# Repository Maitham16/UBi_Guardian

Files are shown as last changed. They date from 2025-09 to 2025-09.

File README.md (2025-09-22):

# UBi-Guardian — Software Stack

Smart edge-AI guardian that senses risks in small aquatic habitats and restores balance with gentle air bursts.  
This repo contains all software pieces: ESP32 firmware, data collector, alerts, dashboard and the ML model assets.

---

## 1) Repo layout

```
/firmware/
  esp32s3.ino                # main firmware (ESP32-S3, Arduino)
  model_data.h               # TFLite model as a C array (included by firmware)
  model_data.cpp             # separate TU
  esp32s3_ripple_classifier.keras # model
  esp32s3_ripple_classifier.tflite # model
/ml/
  train_model.ipynb          # training model
  data_preprocessing.py      # prepare data to train
/server/
  main.py                    # FastAPI collector + CSV logging + Discord alerts
  data_preprocessing.py      # one time script
  Data_collector_phase_1.py  # early phase script for data collector
  dashboard.html             # zero-dependency, opens in a browser
  data/                      # dataset
    telemetry.csv            # timeseries real recorded data
    events.csv               # alerts & pump recommendations
    telemetry.ndjson         # raw backup
    training.csv             # train dataset
```

---

## 2) Quick start

### A) Collector + Alerts (FastAPI)
Requirements: Python 3.9+.

```bash
cd server
python -m venv .venv
source .venv/bin/activate
pip install fastapi uvicorn requests
```

Discord alerts:
- The server already includes a **built-in default webhook URL** in `main.py` (you can replace the `DEFAULT_WEBHOOK` string).
- Alternatively set an env var to override at runtime:
  ```bash
  export DISCORD_WEBHOOK_URL="https://discord.com/api/webhooks/XXX/YYY"
  ```

Run:
```bash
uvicorn main:app --host 0.0.0.0 --port 5001
```

You now have:
- POST `http://<server>:5001/ingest`  # device posts telemetry here
- GET  `/health`, `/latest`, `/export.csv`, `/events.csv`
- POST `/alert/test` (sends a demo alert to Discord)
- POST `/alert/webhook` (persist a new webhook if no env var is set)

> Data files are written to `server/data/` (created automatically).

---

### B) Firmware (ESP32-S3, Arduino)
1. Open **Arduino IDE** (2.x), install:
   - **ESP32** board support, select an **ESP32-S3** dev board.
   - Libraries: `OneWire`, `DallasTemperature`, `Adafruit AHTX0`, `Adafruit VEML7700`, `Adafruit MLX90614`, `Adafruit BMP085/BMP180`, `ESPmDNS`, `Preferences`.

2. Pins (as in the code):
   - I²C: `SDA=8`, `SCL=9`
   - I²S mic (INMP441): `BCLK=18`, `LRCL=17`, `DIN=16`, `SAMPLE_RATE=16000`
   - Relay: `GPIO15`
   - OneWire DS18B20: `GPIO6`
   - TDS ADC pin: `GPIO4`

3. ML model embedding (already provided):
   - We ship `model_data.h/.cpp` with `esp32s3_ripple_classifier_tflite` byte array.
   - If you retrain: regenerate the header from the `.tflite`:
     ```bash
     xxd -i esp32s3_ripple_classifier.tflite > firmware/model_data.h
     ```
     (Keep the exported symbol name unchanged.)

4. Flash `esp32s3.ino`.

#### Device web API (on the ESP32)
- If it can’t join Wi-Fi, it opens AP **`UBiGuardian-Setup`** (captive portal at `192.168.4.1`) to save your SSID/password.
- In STA mode:
  - `GET /` # live status page
  - `GET /sensors` # telemetry JSON snapshot
  - `GET /ml`, `/caps`, `/health`
  - `POST /pump?on=1&sec=10` (manual pump control)
  - `POST /collector?host=<RaspberryPi_IP>&port=5001&path=/ingest`  
    **Important:** point the device to your server’s IP/port/path so it can POST telemetry.

example of our data ingest curl 
    "http://ubiguard.local/collector?host=10.10.216.221&port=5001&path=/ingest"

The device posts once per second; JSON fields match the CSV headers listed below.

---

### C) Dashboard
- Open `dashboard/dashboard.html` directly in your browser (no server needed).
- In the top-right **Base** box, enter your collector base (if not default) and click **Save**.  
  The dashboard will persist this and your chosen **time range** in `localStorage`.
- Panels:
  - **System Snapshot**: shows current state. The **Alert** tile turns **red** for 5 seconds after any alert, **green** otherwise.
  - Charts: **C\* DO**, **micRMS**, **Lux**, **TDS** (auto-downsampled for performance).
  - **All Sensors**: key–value card grid.
  - **Recent Events**: table of alerts and recommendations.
- CSV exports: **Export CSV** and **Events CSV** buttons.

---

## 3) Data schema

Every /ingest POST (and CSV row) uses these keys:

```
ts (epoch seconds) | ms (device ms) | pump | manual_override | alert | reason | context
rec_ms | tTop | tMid | tBot | dT_tb | pressure_hPa | lux | irObj | irAmb
airT | airRH | tds_mV | tds_sat | micRMS | DOproxy | ml_on | ml_pred | ml_conf | ml_used
```

- The collector coerces types, appends a line to `telemetry.csv`, and—if `alert==true` **or** `rec_ms>0`—to `events.csv`.
- Discord messages are compact tables with the most relevant fields (deduped for 60s to avoid spam).

**Example POST to test without hardware:**
```bash
curl -X POST http://<server>:5001/ingest   -H "content-type: application/json"   -d '{
    "ts": '"$(date +%s)"',
    "pump": false, "manual_override": false,
    "alert": true, "reason": "demo_alert", "context": "day",
    "rec_ms": 0,
    "tTop": 23.6, "tMid": 23.5, "tBot": 23.4, "dT_tb": 0.2,
    "pressure_hPa": 1007.8, "lux": 120.0, "micRMS": 3.2,
    "tds_mV": 420, "tds_sat": false, "DOproxy": 6.9,
    "ml_on": true, "ml_pred": "disturbance", "ml_conf": 0.91, "ml_used": true
  }'
```

To send a demo alert embed to Discord:
```bash
curl -X POST http://<server>:5001/alert/test
```

---

## 4) Machine learning model

- Notebook: `ml/train_model.ipynb` trains a multi-class classifier on features:
  `micRMS, lux, ΔT (top–bot), ΔT over 60s at mid, DO* proxy, ΔTDS`.
- Export to TFLite: `esp32s3_ripple_classifier.tflite`.
- Embedded in firmware via `model_data.h` as `esp32s3_ripple_classifier_tflite`.
- Interpreter: TFLM with ops resolver (FullyConnected, Reshape, Softmax, Quantize, Dequantize).  
  Input accepts float/quantized; output is class scores for:
  ```
  calm, cold-shock, cooling-hot, disturbance, flashlight-night,
  glare, human-tap, manual-override, other, pump-self, tds-spike, uniform-overheat
  ```

---

## 5) Operating logic (firmware summary)

- **Sensors**: 3× DS18B20 (top/mid/bot), AHT (air T/RH), VEML7700 (lux), MLX90614 (IR), BMP180/085 (pressure), INMP441 I²S mic (RMS), TDS analog.
- **Derived signals**: calm baseline (micRMS), stratification/inversion, DO* proxy (temp+pressure), barometric drop, flashlight/night spikes, TDS spikes, tap/disturbance timing windows.
- **Pump policy**:
  - Gentle bursts at night if water is calm and DO* borderline.
  - Stronger/longer bursts for stratification, inversion, or overheating.
  - Caps: per-hour and per-night duty.
  - Blockers: sensor fault, heater lamp glare/hot IR, abrupt darkness, cold shock, TDS spike, human tap, pump self-masking.
- **ML gate** (optional): if `cfg.ml_gate==true` the model can override/confirm ripple/tap/flashlight detection; result is recorded in telemetry.

---

## 6) Configuration

Runtime config is persisted in ESP32 `Preferences` and exposed via HTTP:

- `GET /config/get` # JSON
- `POST /config/set?key=<k>&val=<v>` # update a single key  
  Keys include: `do_lo`, `do_hi`, `night_lux`, `glare_lux`, `dt_strat`, `dt_inv`,  
  `overheat_un`, `cap_hour_ms`, `cap_night_ms`, `cool_on_c`, `cool_off_c`, `cool_burst_ms`,  
  `day_on_factor`, `sudden_light_factor`, `sudden_dark_factor`, `sudden_window_ms`,  
  `sunrise_grace_ms`, `ml_gate`.

DS18B20 mapping:
- `GET /dsmap` view known addresses;  
- `POST /dsmap/byindex?top=0&mid=1&bot=2` or `/dsmap/setaddr?top=<hex16>&mid=<hex16>&bot=<hex16>`.

---

## 7) Dashboard tips

- Use the **Range** control to pick `15m to 30d` or **Custom** (From/To).
- The selection **persists** across refreshes.
- Alert tile stays **red for 5 seconds** after any alert; otherwise green.

---

## 8) Deployment notes

- Put the collector on a stable host (Raspberry Pi, mini-PC, VM).  
- Keep the ESP32 and server on the same network or reachable over UDP-to-TCP NATs.
- If you rotate the Discord webhook, either update `DEFAULT_WEBHOOK` in `main.py` or run with the `DISCORD_WEBHOOK_URL` env var.

---

## 9) Troubleshooting

- **No data in dashboard:** confirm the **Base** URL points to the collector and `/export.csv` returns a file.  
- **Device not posting:** visit the device IP  `/` works? Then `POST /collector?host=<server_ip>&port=5001&path=/ingest`.  
- **Bad sensor values:** `/sensors` on the device shows raw readings; check wiring and I²C addresses.

---

## 10) License & attribution

- **Code**: [Apache-2.0](./LICENSE)  
- **Docs & media**: [CC BY-NC 4.0](./LICENSE-DOCS)

Unless stated otherwise in a file header, source **code** is Apache-2.0; **documentation and images** are CC BY-NC 4.0.

Designed by the Edge Computing research team, supervised by Dr. Atakan Aral.

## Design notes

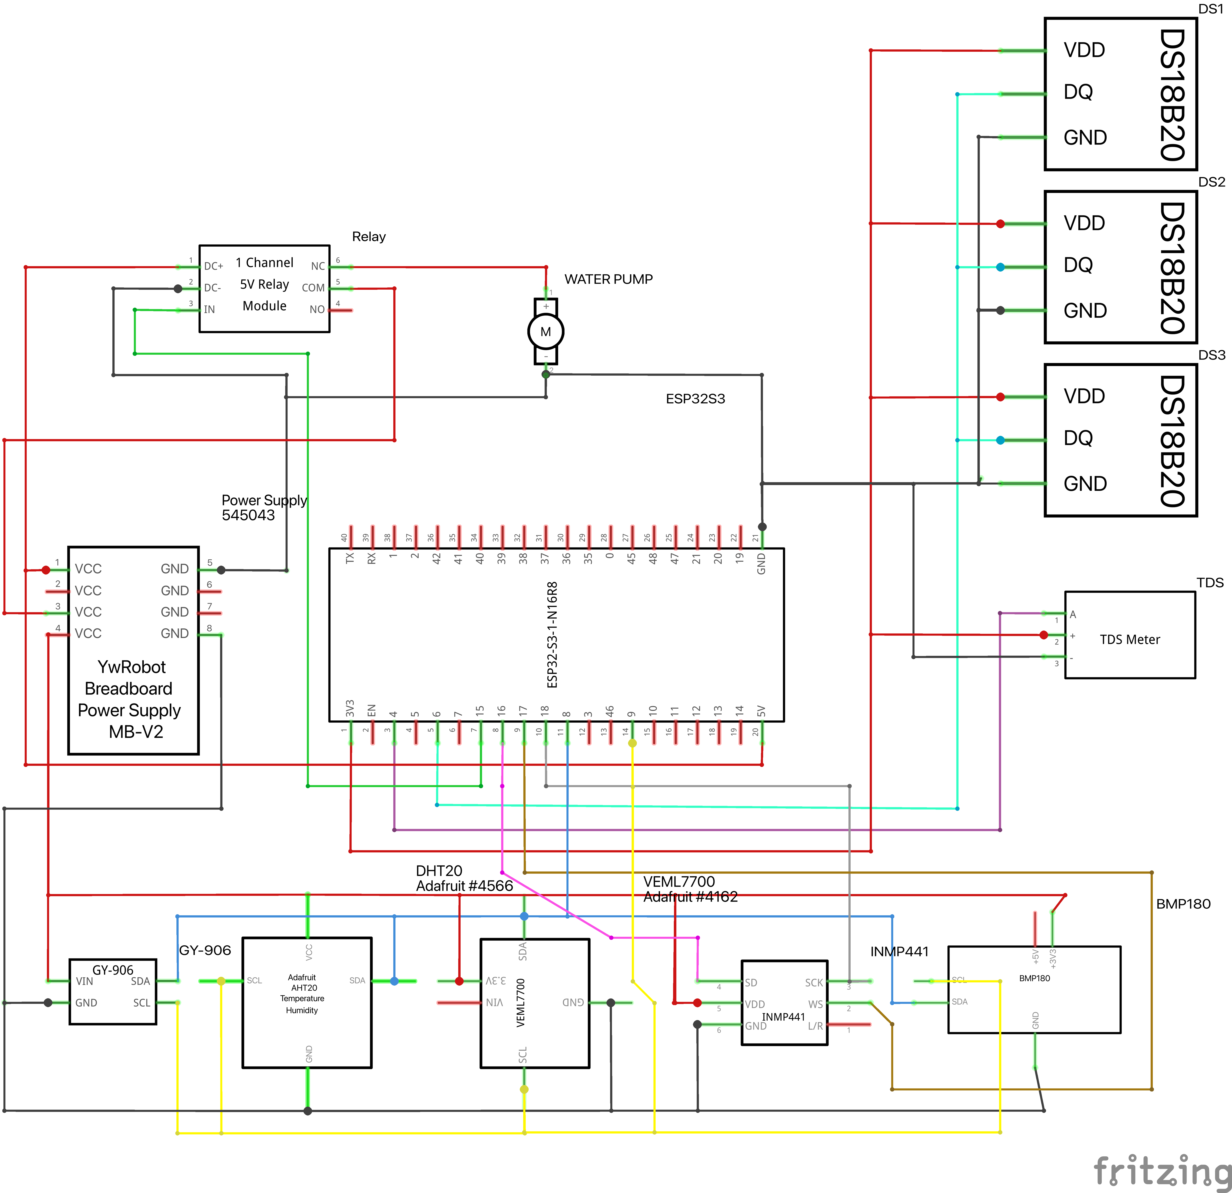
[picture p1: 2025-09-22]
hw_design/UBi_Guardian_schem.png

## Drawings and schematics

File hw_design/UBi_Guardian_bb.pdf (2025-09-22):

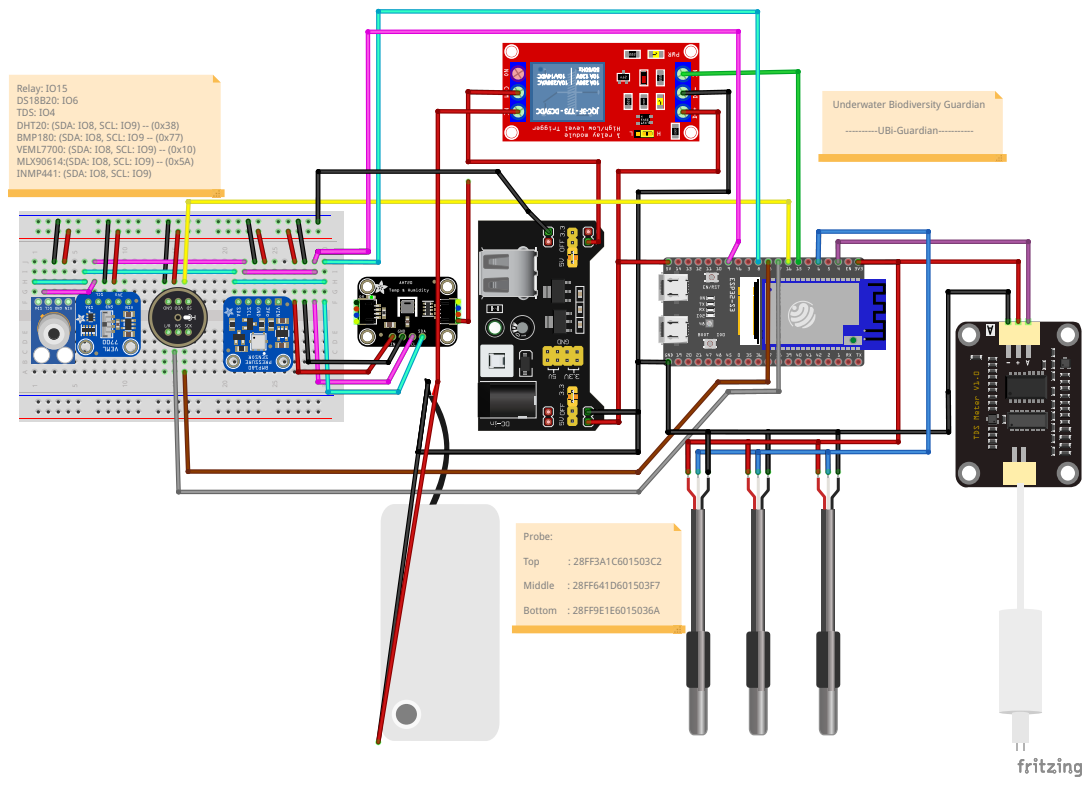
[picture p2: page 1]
Relay: IO15 DS18B20: IO6 TDS: IO4 DHT20: (SDA: IO8, SCL: IO9) -- (0x38) BMP180: (SDA: IO8, SCL: IO9 -- (0x77) VEML7700: (SDA: IO8, SCL: IO9) -- (0x10) MLX90614:(SDA: IO8, SCL: IO9) -- (0x5A) INMP441: (SDA: IO8, SCL: IO9); ----------UBi-Guardian-----------; Probe:; Top; Middle : 28FF641D601503F7; Bottom : 28FF9E1E6015036A

Underwater Biodiversity Guardian

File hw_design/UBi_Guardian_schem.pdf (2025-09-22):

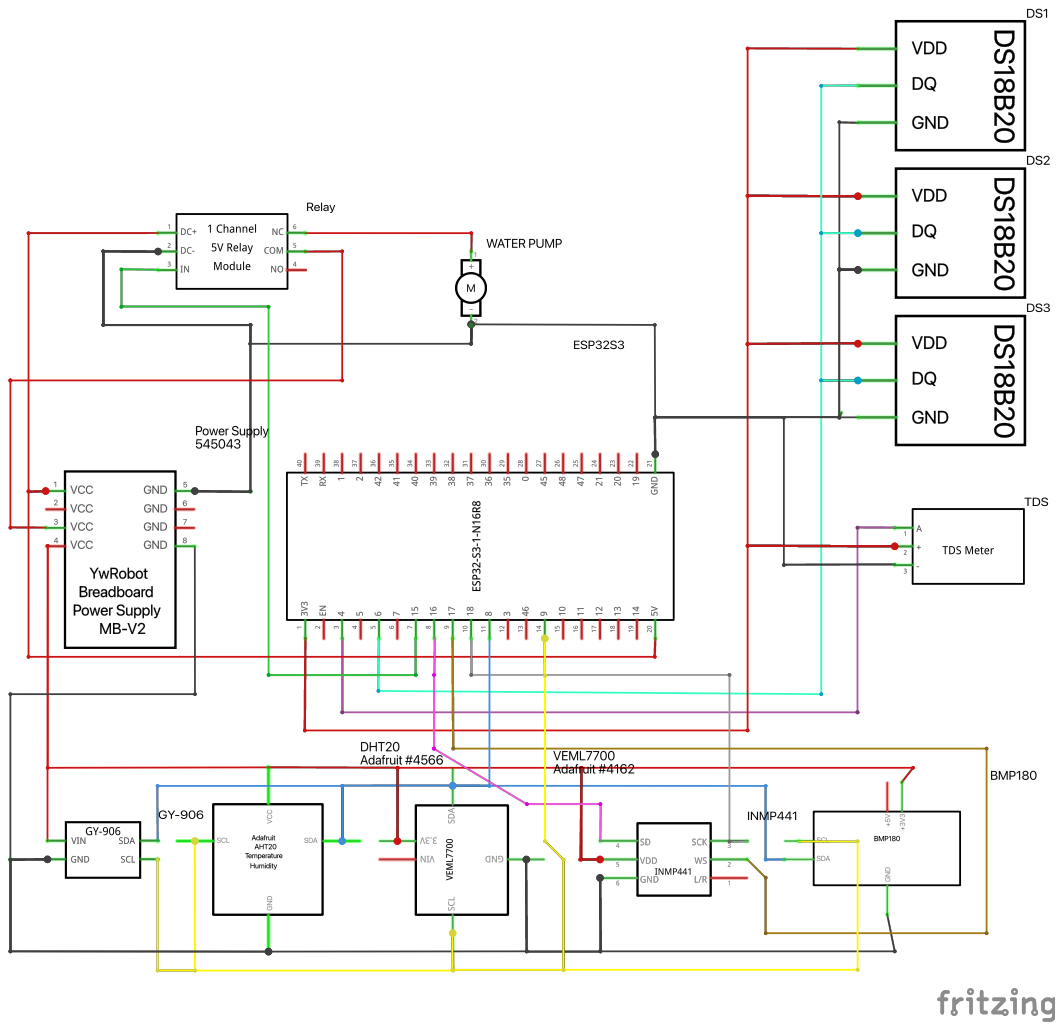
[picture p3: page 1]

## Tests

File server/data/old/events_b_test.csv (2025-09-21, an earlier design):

ts | ms | pump | manual_override | alert | reason | rec_ms | tTop | tMid | tBot | dT_tb | pressure_hPa | lux | irObj | irAmb | airT | airRH | tds_mV | tds_sat | micRMS | DOproxy
1758327555.1464279 | 101004 | False | False | True | tds_spike | 0 | 23.87 | 23.87 | 23.87 | 0.0 | 1003.7 | 159.7 | 25.79 | 24.55 | 24.3 | 59 | 405 | False | 0.0 | 8.35
1758327556.1585479 | 102012 | False | False | True | tds_spike | 0 | 23.87 | 23.87 | 23.87 | 0.0 | 1003.7 | 159.8 | 25.79 | 24.55 | 24.3 | 59 | 406 | False | 0.0 | 8.35
1758327557.151773 | 103004 | False | False | True | tds_spike | 0 | 23.94 | 23.94 | 23.87 | 0.06 | 1003.7 | 159.6 | 25.79 | 24.57 | 24.3 | 59 | 407 | False | 0.0 | 8.34
1758327558.158172 | 104012 | False | False | True | tds_spike | 0 | 23.87 | 23.87 | 23.87 | 0.0 | 1003.7 | 159.6 | 25.79 | 24.55 | 24.3 | 59 | 411 | False | 0.0 | 8.35
1758327559.148154 | 105004 | False | False | True | tds_spike | 0 | 23.87 | 23.94 | 23.87 | 0.0 | 1003.7 | 159.6 | 25.79 | 24.53 | 24.3 | 59 | 409 | False | 5.16 | 8.34
1758327560.161794 | 106012 | False | False | True | tds_spike | 0 | 23.94 | 23.94 | 23.87 | 0.06 | 1003.6 | 159.6 | 25.79 | 24.55 | 24.3 | 59 | 407 | False | 0.0 | 8.34
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

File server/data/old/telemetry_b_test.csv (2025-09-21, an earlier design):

ts | ms | pump | manual_override | alert | reason | rec_ms | tTop | tMid | tBot | dT_tb | pressure_hPa | lux | irObj | irAmb | airT | airRH | tds_mV | tds_sat | micRMS | DOproxy
1758298827.302067 | 10025 | False | False | False | none | 0 | 24.94 | 24.94 | 24.87 | 0.06 | 1004.7 | 190.9 | 27.03 | 24.65 | 25.9 | 58 | 446 | False | 0.0 | 8.19
1758298828.305867 | 11033 | False | False | False | none | 0 | 24.94 | 24.94 | 24.87 | 0.06 | 1004.6 | 190.9 | 27.11 | 24.65 | 25.9 | 58 | 433 | False | 0.0 | 8.19
1758298829.549473 | 12025 | False | False | False | none | 0 | 24.94 | 24.94 | 24.94 | 0.0 | 1004.7 | 191.0 | 27.05 | 24.63 | 25.9 | 58 | 430 | False | 0.0 | 8.19
1758298830.3940952 | 13033 | False | False | False | none | 0 | 24.94 | 25.0 | 24.94 | 0.0 | 1004.6 | 191.0 | 27.17 | 24.65 | 25.9 | 58 | 446 | False | 0.0 | 8.18
1758298831.4943 | 14025 | False | False | False | none | 0 | 24.94 | 24.94 | 24.94 | 0.0 | 1004.7 | 191.1 | 27.03 | 24.63 | 25.9 | 58 | 432 | False | 0.0 | 8.19
1758298832.307418 | 15033 | False | False | False | none | 0 | 24.94 | 24.94 | 24.94 | 0.0 | 1004.7 | 191.1 | 27.03 | 24.65 | 25.9 | 58 | 446 | False | 0.0 | 8.19
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

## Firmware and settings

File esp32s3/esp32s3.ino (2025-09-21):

#include <Arduino.h>
#include <WiFi.h>
#include <WebServer.h>
#include <DNSServer.h>
#include <Preferences.h>
#include <ESPmDNS.h>
#include <HTTPClient.h>
#include <math.h>
#include <Wire.h>
#include <OneWire.h>
#include <DallasTemperature.h>
#include <Adafruit_BMP085.h>
#include <Adafruit_Sensor.h>
#include <Adafruit_AHTX0.h>
#include <Adafruit_VEML7700.h>
#include <Adafruit_MLX90614.h>
#include "driver/i2s.h"
#include <memory>
#include "model_data.h"
#include "tensorflow/lite/micro/micro_interpreter.h"
#include "tensorflow/lite/micro/micro_mutable_op_resolver.h"
#include "tensorflow/lite/schema/schema_generated.h"
#include "tensorflow/lite/c/common.h"

#define RELAY_PIN       15
#define ONE_WIRE_PIN    6
#define TDS_PIN         4
#define I2C_SDA         8
#define I2C_SCL         9
#define I2S_PORT        I2S_NUM_0
#define I2S_BCLK_PIN    18
#define I2S_LRCL_PIN    17
#define I2S_DIN_PIN     16
#define I2S_SAMPLE_RATE 16000
#define I2S_SAMPLES     2048

Preferences prefs;
WebServer  server(80);
DNSServer  dns;
bool apMode = false;
unsigned long lastConnCheck = 0, disconnectedSince = 0;
const unsigned long RECHECK_MS = 3000, DISCONNECT_GRACE_MS = 15000;
const char* MDNS_NAME = "ubiguard";
const char* AP_SSID   = "UBiGuardian-Setup";
const IPAddress AP_IP(192,168,4,1), AP_GW(192,168,4,1), AP_MASK(255,255,255,0);

String   collHost = "";
uint16_t collPort = 5001;
String   collPath = "/ingest";
bool     pushEnabled = true;

OneWire oneWire(ONE_WIRE_PIN);
DallasTemperature ds18b20(&oneWire);
Adafruit_BMP085   bmp;
Adafruit_AHTX0    aht;
Adafruit_VEML7700 veml;
Adafruit_MLX90614 mlx = Adafruit_MLX90614();

bool bmpOK=false, ahtOK=false, vemlOK=false, mlxOK=false, i2sOK=false;

volatile bool pump_active = false;
unsigned long pump_off_at = 0;
bool manual_override = false;
unsigned long pump_on_at = 0;

const uint32_t STRAT_DWELL_MS    = 60000UL;
const float    RMS_MULT          = 2.0f;
const float    DT60_COLD         = -0.5f;
const float    TDS_JUMP_ABS_MV   = 200.0f;
const float    TDS_JUMP_FRAC     = 0.25f;
const uint32_t TDS_DWELL_MS      = 10000UL;
const float    IR_DELTA_HOT      = 5.0f;
const float    IR_ABS_HOT        = 45.0f;
const float    AIR_FIRE_ABS      = 50.0f;
const float    AIR_HOT_T         = 40.0f;
const float    AIR_HOT_LOW_RH    = 15.0f;
const int      PBUF_MAX          = 190;
const float    P_DROP_HPA        = 6.0f;
const uint32_t GENTLE_SEC        = 10;
const uint32_t GENTLE_COOLDOWN   = 5UL*60UL*1000UL;
const uint32_t PUMP_SELF_MASK_MS = 8000UL;
const uint32_t MIN_ON_MS         = 5000UL;
const int      SENSOR_FAULT_SEC  = 5;
const uint32_t HOUR_WINDOW_MS    = 60UL*60UL*1000UL;
const uint32_t TAP_MIN_MS        = 700UL;
const uint32_t TAP_MAX_MS        = 2000UL;
const uint32_t DISTURB_DWELL_MS  = 5000UL;
const uint32_t LUX_WIN_SEC       = 5;
const uint32_t SUDDEN_HOLD_MS    = 3000UL;

struct Config {
  float do_lo=5.0, do_hi=7.0;
  float night_lux=30.0, glare_lux=2000.0;
  float dt_strat=1.0, dt_inv=-0.8;
  float overheat_un=30.0;
  uint32_t cap_hour_ms  = 30UL*60UL*1000UL;
  uint32_t cap_night_ms = 3UL*60UL*60UL*1000UL;
  float    cool_on_c=30.0, cool_off_c=29.5;
  uint32_t cool_burst_ms=20000UL;
  float day_on_factor=5.0f;
  float sudden_light_factor=10.0f;
  float sudden_dark_factor =0.2f;
  uint32_t sudden_window_ms=3000UL;
  uint32_t sunrise_grace_ms=10UL*60UL*1000UL;
  bool ml_gate=false;
} cfg;

void cfgSave(){
  prefs.begin("cfg", false);
  prefs.putFloat("do_lo", cfg.do_lo);      prefs.putFloat("do_hi", cfg.do_hi);
  prefs.putFloat("night", cfg.night_lux);  prefs.putFloat("glare", cfg.glare_lux);
  prefs.putFloat("dts", cfg.dt_strat);     prefs.putFloat("dti", cfg.dt_inv);
  prefs.putFloat("oh", cfg.overheat_un);
  prefs.putULong("cap_h", cfg.cap_hour_ms); prefs.putULong("cap_n", cfg.cap_night_ms);
  prefs.putFloat("cool_on", cfg.cool_on_c); prefs.putFloat("cool_off", cfg.cool_off_c);
  prefs.putULong("cool_ms", cfg.cool_burst_ms);
  prefs.putFloat("day_fact", cfg.day_on_factor);
  prefs.putFloat("sud_l", cfg.sudden_light_factor);
  prefs.putFloat("sud_d", cfg.sudden_dark_factor);
  prefs.putULong("sud_w", cfg.sudden_window_ms);
  prefs.putULong("sunrise", cfg.sunrise_grace_ms);
  prefs.putBool("ml", cfg.ml_gate);
  prefs.end();
}
void cfgLoad(){
  prefs.begin("cfg", true);
  cfg.do_lo     = prefs.getFloat("do_lo", cfg.do_lo);
  cfg.do_hi     = prefs.getFloat("do_hi", cfg.do_hi);
  cfg.night_lux = prefs.getFloat("night", cfg.night_lux);
  cfg.glare_lux = prefs.getFloat("glare", cfg.glare_lux);
  cfg.dt_strat  = prefs.getFloat("dts", cfg.dt_strat);
  cfg.dt_inv    = prefs.getFloat("dti", cfg.dt_inv);
  cfg.overheat_un = prefs.getFloat("oh", cfg.overheat_un);
  cfg.cap_hour_ms  = prefs.getULong("cap_h", cfg.cap_hour_ms);
  cfg.cap_night_ms = prefs.getULong("cap_n", cfg.cap_night_ms);
  cfg.cool_on_c    = prefs.getFloat("cool_on", cfg.cool_on_c);
  cfg.cool_off_c   = prefs.getFloat("cool_off", cfg.cool_off_c);
  cfg.cool_burst_ms= prefs.getULong("cool_ms", cfg.cool_burst_ms);
  cfg.day_on_factor      = prefs.getFloat("day_fact", cfg.day_on_factor);
  cfg.sudden_light_factor= prefs.getFloat("sud_l", cfg.sudden_light_factor);
  cfg.sudden_dark_factor = prefs.getFloat("sud_d", cfg.sudden_dark_factor);
  cfg.sudden_window_ms   = prefs.getULong("sud_w", cfg.sudden_window_ms);
  cfg.sunrise_grace_ms   = prefs.getULong("sunrise", cfg.sunrise_grace_ms);
  cfg.ml_gate   = prefs.getBool("ml", cfg.ml_gate);
  prefs.end();
}
String cfgJSON(){
  String j="{";
  j+="\"do_lo\":"+String(cfg.do_lo)+",\"do_hi\":"+String(cfg.do_hi)
   +",\"night_lux\":"+String(cfg.night_lux)+",\"glare_lux\":"+String(cfg.glare_lux)
   +",\"dt_strat\":"+String(cfg.dt_strat)+",\"dt_inv\":"+String(cfg.dt_inv)
   +",\"overheat_un\":"+String(cfg.overheat_un)
   +",\"cap_hour_ms\":"+String(cfg.cap_hour_ms)+",\"cap_night_ms\":"+String(cfg.cap_night_ms)
   +",\"cool_on_c\":"+String(cfg.cool_on_c)+",\"cool_off_c\":"+String(cfg.cool_off_c)
   +",\"cool_burst_ms\":"+String(cfg.cool_burst_ms)
   +",\"day_on_factor\":"+String(cfg.day_on_factor)
   +",\"sudden_light_factor\":"+String(cfg.sudden_light_factor)
   +",\"sudden_dark_factor\":"+String(cfg.sudden_dark_factor)
   +",\"sudden_window_ms\":"+String(cfg.sudden_window_ms)
   +",\"sunrise_grace_ms\":"+String(cfg.sunrise_grace_ms)
   +",\"ml_gate\":"+(cfg.ml_gate?String("true"):String("false"))+"}";
  return j;
}

bool   bl_ready=false;
float  rms_base=0, lux_base=0, lux_night_base=0, tds_base=0, p_ref=1013.25f;
unsigned long bl_start_ms=0;
unsigned long hour_window_start_ms = 0;
uint32_t duty_ms_hour = 0, duty_ms_night = 0;
bool      was_dark = false;
unsigned long last_gentle_ms = 0;
const int SLOPE_WIN=60; float mid_hist[SLOPE_WIN]; int mid_idx=0, mid_cnt=0;
unsigned long strat_since=0, inv_since=0;
unsigned long disturb_since=0;
unsigned long tds_since=0;
int fault_cnt=0;
bool is_day=false;
unsigned long day_switch_ms=0;
unsigned long abrupt_dark_since=0;

struct LuxSample { unsigned long ms; float lux; };
LuxSample luxbuf[LUX_WIN_SEC+1]; int lhead=0; int lsize=0;

struct PEntry { unsigned long ms; float p; };
PEntry pbuf[PBUF_MAX]; int phead=0; int psize=0; unsigned long last_pbuf_min_mark=0;

bool   cur_alert = false;
String cur_reason = "none";
String cur_ctx = "night";

typedef uint8_t DeviceAddress[8];
DeviceAddress addrTop, addrMid, addrBot;
bool haveMap=false;

alignas(16) static uint8_t tensor_arena[200 * 1024];
const tflite::Model* tfl_model = nullptr;
tflite::MicroMutableOpResolver<5> tfl_ops;

std::unique_ptr<tflite::MicroInterpreter> tfl;
TfLiteTensor* tfl_in = nullptr;
TfLiteTensor* tfl_out = nullptr;
const char* kClasses[] = {
  "calm","cold-shock","cooling-hot","disturbance","flashlight-night",
  "glare","human-tap","manual-override","other","pump-self",
  "tds-spike","uniform-overheat"
};
constexpr int kNumClasses = sizeof(kClasses)/sizeof(kClasses[0]);

volatile int   ml_last_idx  = -1;
volatile float ml_last_conf = 0.f;
volatile bool  ml_used      = false;
const char* label_from_idx(int i){ return (i>=0 && i<kNumClasses)? kClasses[i] : "n/a"; }

String addrToHex(const DeviceAddress a){
  char hex[17]; for(int j=0;j<8;j++) sprintf(&hex[j*2], "%02X", a[j]); hex[16]=0; return String(hex);
}
bool hexToAddr(const String& s, DeviceAddress a){
  if(s.length()!=16) return false;
  for(int i=0;i<8;i++){ char b[3]={ (char)s[2*i], (char)s[2*i+1], 0 }; a[i]=strtoul(b,nullptr,16); }
  return true;
}
bool getAddrByIndex(int idx, DeviceAddress a){ return ds18b20.getAddress(a, idx); }
void saveAddr(const char* key, const DeviceAddress a){ prefs.putString(key, addrToHex(a)); }
bool loadDSMap(){
  prefs.begin("dsmap", true);
  String t=prefs.getString("top",""), m=prefs.getString("mid",""), b=prefs.getString("bot","");
  prefs.end();
  if(t.length()==16 && m.length()==16 && b.length()==16){
    haveMap = hexToAddr(t,addrTop) && hexToAddr(m,addrMid) && hexToAddr(b,addrBot);
  } else haveMap=false;
  return haveMap;
}
void persistDSMap(){
  prefs.begin("dsmap", false);
  saveAddr("top", addrTop); saveAddr("mid", addrMid); saveAddr("bot", addrBot);
  prefs.end();
}
void initOrPersistDSMap(){
  if(loadDSMap()) return;
  DeviceAddress at, am, ab;
  if(getAddrByIndex(0,at) && getAddrByIndex(1,am) && getAddrByIndex(2,ab)){
    memcpy(addrTop,at,8); memcpy(addrMid,am,8); memcpy(addrBot,ab,8);
    persistDSMap(); haveMap=true;
  } else haveMap=false;
}
float readTempRole(const DeviceAddress a, int fallbackIndex){
  if(haveMap) return ds18b20.getTempC(a);
  else return ds18b20.getTempCByIndex(fallbackIndex);
}
static inline bool i2cPresent(uint8_t addr){
  Wire.beginTransmission(addr);
  return Wire.endTransmission()==0;
}
bool i2cRecover() {
  Wire.end(); delay(5);
  Wire.begin(I2C_SDA, I2C_SCL);
  Wire.setClock(50000);
  Wire.setTimeOut(200);
  return true;
}
template<typename F>
bool i2cTry(uint8_t addr, F fn){
  if(!i2cPresent(addr)) return false;
  if(fn()) return true;
  i2cRecover(); delay(5);
  return (i2cPresent(addr) && fn());
}
bool i2sInit(){
  i2s_config_t cfgI = {
    .mode = (i2s_mode_t)(I2S_MODE_MASTER | I2S_MODE_RX),
    .sample_rate = I2S_SAMPLE_RATE,
    .bits_per_sample = I2S_BITS_PER_SAMPLE_32BIT,
    .channel_format = I2S_CHANNEL_FMT_ONLY_LEFT,
    .communication_format = (i2s_comm_format_t)(I2S_COMM_FORMAT_I2S | I2S_COMM_FORMAT_I2S_MSB),
    .intr_alloc_flags = ESP_INTR_FLAG_LEVEL1,
    .dma_buf_count = 6,
    .dma_buf_len = 256,
    .use_apll = false,
    .tx_desc_auto_clear = false,
    .fixed_mclk = 0
  };
  i2s_pin_config_t pins = {
    .bck_io_num = I2S_BCLK_PIN,
    .ws_io_num  = I2S_LRCL_PIN,
    .data_out_num = I2S_PIN_NO_CHANGE,
    .data_in_num  = I2S_DIN_PIN
  };
  if (i2s_driver_install(I2S_PORT, &cfgI, 0, NULL) != ESP_OK) return false;
  if (i2s_set_pin(I2S_PORT, &pins) != ESP_OK) return false;
  return true;
}
float micRMS(){
  static int32_t buf[I2S_SAMPLES];
  size_t br=0;
  if(i2s_read(I2S_PORT,(void*)buf,sizeof(buf),&br,pdMS_TO_TICKS(50))!=ESP_OK) return NAN;
  int n=br/sizeof(int32_t); if(n<=0) return NAN;
  double acc=0; for(int i=0;i<n;i++){ int32_t s=buf[i]>>8; acc += (double)s*s; }
  return (float)(sqrt(acc/n)/2048.0);
}
int median5i(int a,int b,int c,int d,int e){
  int v[5]={a,b,c,d,e};
  for(int i=0;i<4;i++) for(int j=i+1;j<5;j++) if(v[j]<v[i]){int t=v[i];v[i]=v[j];v[j]=t;}
  return v[2];
}
float tds_mV(bool &sat){
  analogSetPinAttenuation(TDS_PIN, ADC_11db);
  int m0=analogReadMilliVolts(TDS_PIN); delay(2);
  int m1=analogReadMilliVolts(TDS_PIN); delay(2);
  int m2=analogReadMilliVolts(TDS_PIN); delay(2);
  int m3=analogReadMilliVolts(TDS_PIN); delay(2);
  int m4=analogReadMilliVolts(TDS_PIN);
  int mv=median5i(m0,m1,m2,m3,m4);
  sat = (mv>3000);
  return (float)mv;
}
static inline float o2sol_mLL_fresh(float T_C){
  const double A0=2.00856, A1=3.22400, A2=3.99063, A3=4.80299, A4=0.978188, A5=1.71069;
  const double B0=-6.24097e-3, B1=-6.93498e-3, B2=-6.90358e-3, B3=-4.29155e-3, C0=-3.11680e-7;
  double Ts = log((298.15 - (double)T_C) / (273.15 + (double)T_C));
  double A = ((((A5*Ts + A4)*Ts + A3)*Ts + A2)*Ts + A1)*Ts + A0;
  double B = ((B3*Ts + B2)*Ts + B1)*Ts + B0;
  double mLL = exp(A);
  return (float)mLL;
}
static inline float sat_vapor_kPa(float T_C){ return 0.61078f * expf(17.27f * T_C / (T_C + 237.3f)); }
static inline float o2sat_mgL_local(float T_C, float P_hPa){
  if (isnan(T_C) || isnan(P_hPa) || T_C < -1.0f || T_C > 45.0f) return NAN;
  float mgL_1atm = o2sol_mLL_fresh(T_C) * 1.429f;
  float pw_kPa = sat_vapor_kPa(T_C);
  float pdry_kPa = max(0.0f, (P_hPa*0.1f) - pw_kPa);
  float pdry_ref = 101.325f - pw_kPa;
  float factor = (pdry_ref>0.0f) ? (pdry_kPa / pdry_ref) : 1.0f;
  return mgL_1atm * factor;
}
void pumpOn(){  digitalWrite(RELAY_PIN, HIGH); }
void pumpOff(){ digitalWrite(RELAY_PIN, LOW);  }
bool pumpIsOn(){ return digitalRead(RELAY_PIN)==HIGH; }
String jnum(float v, int digits){ if (isnan(v)) return "null"; String s; s+=String(v, digits); return s; }
String jbool(bool b){ return b ? "true" : "false"; }
static inline uint16_t clamp_port(long v){ if(v<1) return 1; if(v>65535) return 65535; return (uint16_t)v; }
static inline int      clamp_nonneg(long v){ return v<0 ? 0 : (int)v; }
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
void loop(){
  if (Serial.available()){
    char c = Serial.read();
    if (c=='s'){ pumpOn(); pump_active=true; manual_override=true; pump_on_at=millis(); pump_off_at=millis()+3000UL; Serial.println(F("[MANUAL] Short burst (3s)")); }
    else if (c=='l'){ pumpOn(); pump_active=true; manual_override=true; pump_on_at=millis(); pump_off_at=millis()+10000UL; Serial.println(F("[MANUAL] Long burst (10s)")); }
    else if (c=='x'){ pumpOff(); pump_active=false; manual_override=false; pump_off_at=0; Serial.println(F("[MANUAL] Pump OFF")); }
  }

  if (pump_active && pump_off_at!=0 && (long)(millis()-pump_off_at) >= 0){
    pumpOff(); pump_active=false; pump_off_at=0; manual_override=false;
    disturb_since=0; tds_since=0; abrupt_dark_since=0;
    Serial.println(F("[PUMP] Auto OFF"));
  }

  if (apMode){ dns.processNextRequest(); server.handleClient(); }
  else {
    server.handleClient();
    if (millis()-lastConnCheck >= RECHECK_MS){
      lastConnCheck = millis();
      ensurePortalIfDisconnected();
      if (apMode){ server.stop(); MDNS.end(); }
    }
  }

  if (millis()-lastTick >= 1000){
    lastTick = millis();

    ds18b20.requestTemperatures();
    float tTop = readTempRole(addrTop,0);
    float tMid = readTempRole(addrMid,1);
    float tBot = readTempRole(addrBot,2);
    if (tTop==85.0 || tTop<=-100) tTop=NAN;
    if (tMid==85.0 || tMid<=-100) tMid=NAN;
    if (tBot==85.0 || tBot<=-100) tBot=NAN;
    float dT_tb = (isnan(tTop)||isnan(tBot)) ? NAN : (tTop - tBot);

    mid_hist[mid_idx]=tMid; mid_idx=(mid_idx+1)%SLOPE_WIN; if(mid_cnt<SLOPE_WIN) mid_cnt++;
    bool cold_shock=false;
    float dTdt_mid=NAN;
    if(mid_cnt==SLOPE_WIN){
      int oldest = mid_idx;
      float d = tMid - mid_hist[oldest];
      cold_shock = (!isnan(d) && d <= DT60_COLD);
      dTdt_mid = d;
    }

    bool strat_now = (!isnan(dT_tb) && dT_tb > cfg.dt_strat);
    bool inv_now   = (!isnan(dT_tb) && dT_tb < cfg.dt_inv);
    if (strat_now){ if (strat_since==0) strat_since=millis(); } else strat_since=0;
    if (inv_now){ if (inv_since==0)   inv_since=millis(); }   else inv_since=0;
    bool stratified = (strat_since>0 && (millis()-strat_since)>=STRAT_DWELL_MS);
    bool inversion  = (inv_since>0   && (millis()-inv_since)  >=STRAT_DWELL_MS);

    float P_hPa = NAN;
    if (bmpOK && i2cPresent(0x77)) { P_hPa = bmp.readPressure()/100.0f; }
    float P_eff = isnan(P_hPa) ? 1013.25f : P_hPa;
    if (!isnan(P_eff)) pbuf_push(millis(), P_eff);

    float lux = NAN;
    if (vemlOK && i2cPresent(0x10)) { lux = veml.readLux(); }

    float irObj=NAN, irAmb=NAN;
    i2cTry(0x5A, [&](){ irObj=mlx.readObjectTempC(); irAmb=mlx.readAmbientTempC(); return !(isnan(irObj)||isnan(irAmb)); });

    float airT=NAN, airRH=NAN;
    i2cTry(0x38, [&](){ sensors_event_t hum, temp; if(!aht.getEvent(&hum,&temp)) return false; airT=temp.temperature; airRH=hum.relative_humidity; return true; });

    bool tdsSAT = false;
    float tds   = tds_mV(tdsSAT);
    float rms   = i2sOK ? micRMS() : NAN;

    if (!isnan(rms) && rms < 5.0f) rms = 0.0f;

    float doCstar = (!isnan(tMid)) ? o2sat_mgL_local(tMid, P_eff) : NAN;

    float calm_thr_cur = (bl_ready && rms_base > 0) ? (RMS_MULT * rms_base) : 5.0f;
    bool  calm_now     = (!isnan(rms) && rms < calm_thr_cur);

    if (!pump_active && calm_now){
      if (!bl_ready && millis() - bl_start_ms > 10000) bl_ready = true;
      float alpha = bl_ready ? 0.01f : 0.2f;
      if (!isnan(rms) && rms <= calm_thr_cur) rms_base = (1 - alpha) * rms_base + alpha * rms;
      if (!isnan(lux)) {
        lux_base = (1 - alpha) * lux_base + alpha * lux;
        if (!is_day) lux_night_base = (1 - alpha) * lux_night_base + alpha * lux;
      }
      if (!isnan(P_hPa)) p_ref   = (1 - 0.001f) * p_ref + 0.001f * P_hPa;
      if (!isnan(tds))   tds_base = (1 - alpha) * tds_base + alpha * tds;
    }

    float day_on_lux = cfg.night_lux * max(2.0f, cfg.day_on_factor);
    bool was_day = is_day;
    if (!is_day && !isnan(lux) && lux > day_on_lux) { is_day = true; day_switch_ms = millis(); }
    if ( is_day && !isnan(lux) && lux < cfg.night_lux) { is_day = false; day_switch_ms = millis(); }
    bool in_sunrise_grace = (!isnan(lux) && is_day && (millis()-day_switch_ms) < cfg.sunrise_grace_ms);

    lux_push(millis(), isnan(lux)?0.0f:lux);
    float ratio_up=1.0f, ratio_down=1.0f;
    lux_change_ratio(cfg.sudden_window_ms, ratio_up, ratio_down);
    bool night_flashlight = (!is_day && ratio_up >= cfg.sudden_light_factor);
    bool day_abrupt_dark_now = (is_day && ratio_down <= cfg.sudden_dark_factor);
    if (day_abrupt_dark_now){
      if (abrupt_dark_since==0) abrupt_dark_since=millis();
    } else {
      abrupt_dark_since=0;
    }
    bool day_abrupt_dark = (abrupt_dark_since>0 && (millis()-abrupt_dark_since)>=SUDDEN_HOLD_MS);

    float calm_thr = (bl_ready && rms_base>0) ? (RMS_MULT * rms_base) : 5.0f;
    bool calm = (!isnan(rms) && rms < calm_thr);
    bool dark = (!isnan(lux) && lux < cfg.night_lux);

    if ((millis() - hour_window_start_ms) >= HOUR_WINDOW_MS) {
      unsigned long over = (millis() - hour_window_start_ms) % HOUR_WINDOW_MS;
      hour_window_start_ms = millis() - over;
      duty_ms_hour = 0;
    }
    if (pump_active) {
      duty_ms_hour += 1000;
      if (dark) duty_ms_night += 1000;
    }
    static unsigned long bright_since_ms = 0;
    if (dark) { was_dark = true; bright_since_ms = 0; }
    else {
      if (was_dark) {
        if (bright_since_ms==0) bright_since_ms = millis();
        if (millis() - bright_since_ms >= 10UL*60UL*1000UL) {
          duty_ms_night = 0; was_dark = false; bright_since_ms = 0;
        }
      }
    }

    bool tds_spike_now = (bl_ready && !isnan(tds) &&
                          ( (tds - tds_base) > max(TDS_JUMP_ABS_MV, TDS_JUMP_FRAC*tds_base) ));
    if (tds_spike_now){ if (tds_since==0) tds_since=millis(); } else tds_since=0;
    bool tds_spike = (tds_since>0 && (millis()-tds_since)>=TDS_DWELL_MS);

    float drop3h=0; bool have3h = pbuf_drop_over_3h(P_eff, drop3h);
    bool baro_drop = (have3h && drop3h >= P_DROP_HPA && !isnan(tMid) && tMid >= 20.0f);

    bool heater_lamp = (!isnan(lux) && lux>cfg.glare_lux) &&
                       ( (!isnan(irObj) && !isnan(irAmb) && (irObj - irAmb) >= IR_DELTA_HOT) ||
                         (!isnan(irObj) && irObj >= IR_ABS_HOT) );

    bool flashlight_suspicious = night_flashlight && !in_sunrise_grace;
    bool abrupt_dark_hazard    = day_abrupt_dark;

    bool within_self_mask = pump_active && (millis() - pump_on_at) < PUMP_SELF_MASK_MS;
    bool ripple_now = (!isnan(rms) && !isnan(calm_thr) && (rms >= calm_thr)) && !within_self_mask;
    if (ripple_now){
      if (disturb_since==0) disturb_since = millis();
    } else {
      disturb_since = 0;
    }
    bool human_tap = false, disturbance = false;
    if (disturb_since>0){
      uint32_t dur = millis() - disturb_since;
      if (!pump_active && dur >= TAP_MIN_MS && dur <= TAP_MAX_MS) human_tap = true;
      if (dur >= DISTURB_DWELL_MS) disturbance = true;
    }

    bool overheat_un = (!isnan(tMid)  && tMid > cfg.overheat_un && (!isnan(dT_tb) && fabs(dT_tb) < 0.3f));

    bool critical_nan = (isnan(tTop) || isnan(tMid) || isnan(tBot));
    if (critical_nan) fault_cnt++; else fault_cnt=0;
    bool sensor_fault = (fault_cnt >= SENSOR_FAULT_SEC);

    int ml_cls=-1; float ml_conf=0.f; bool ml_ok=false;
    float tds_delta = (bl_ready && !isnan(tds)) ? (tds - tds_base) : 0.f;
    if (cfg.ml_gate && tfl && tfl_in && tfl_out){
      bool used=false;
      bool ripple_before = ripple_now;
      bool tap_before    = human_tap;
      bool flash_before  = flashlight_suspicious;

      ml_ok = ml_predict(rms, lux, dT_tb, dTdt_mid, doCstar, tds_delta, ml_cls, ml_conf);
      if (ml_ok){
        const char* c = kClasses[ml_cls];
        bool is_calm = (strcmp(c,"calm")==0 && ml_conf>=0.7f);
        bool is_dist = (strcmp(c,"disturbance")==0 && ml_conf>=0.6f);
        bool is_tap  = (strcmp(c,"human-tap")==0 && ml_conf>=0.6f);
        bool is_flash= (strcmp(c,"flashlight-night")==0 && ml_conf>=0.6f);
        bool is_pump = (strcmp(c,"pump-self")==0 && ml_conf>=0.6f);

        if (is_calm){ used |= ripple_before; ripple_now=false; disturb_since=0; }
        if (is_dist){ if (!ripple_before){ used=true; } ripple_now=true; if (disturb_since==0) disturb_since=millis(); }
        if (is_tap){  if (!tap_before){ used=true; } human_tap=true; }
        if (is_flash){ if (!flash_before){ used=true; } flashlight_suspicious = flashlight_suspicious || (!is_day); }
        if (is_pump){ used |= (ripple_before || tap_before || flash_before); ripple_now=false; human_tap=false; disturbance=false; disturb_since=0; }

        ml_last_idx  = ml_cls;
        ml_last_conf = ml_conf;
        ml_used      = used;
      }
    }
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

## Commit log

2025-09-21 Final Code of Ubiguard (Underwater Biodiversity Guardian) For The Challenge
    [events.csv, events_b_test.csv, events_old.csv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]
2025-09-22 Add Bill of Materials for UBi_Guardian project
    - Created HTML file UBi_Guardian_bom.html containing the assembly list and shopping list for the UBi_Guardian project.
    - Included details such as part labels, manufacturer numbers, part types, and properties for each component.
    - Structured the document with appropriate headings and tables for clarity.
    [events.csv, telemetry.csv]
2025-09-22 fix the design and add fzz
    [UBi_Guardian.fzz]
2025-09-22 Update UBi_Guardian.fzz with new design changes
    [UBi_Guardian.fzz]
2025-09-22 fix the design
    [UBi_Guardian.fzz]
2025-09-22 refactor the folders
    [UBi_Guardian.fzz]
2025-09-22 fix folders and files layout
    [events.csv, events_b_test.csv, events_old.csv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]
2025-09-26 Update according to Arman's feedback
    [events.csv, telemetry.csv]
